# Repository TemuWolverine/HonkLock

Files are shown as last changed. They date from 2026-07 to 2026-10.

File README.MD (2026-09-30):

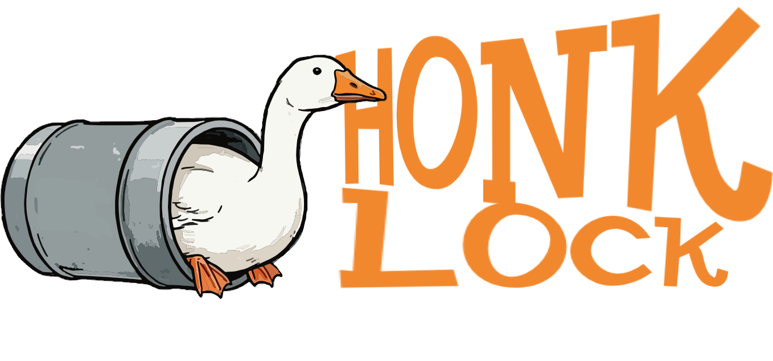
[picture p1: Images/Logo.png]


Watch the video (https://youtu.be/xcAHMuf7iR8)

- [Electronics](#electronics)
  - [Brain board](#brain-board)
  - [Sensor Board](#sensor-board)
  - [Hardware](#hardware)
  - [Power](#power)
  - [Alternative power wiring](#alternative-power-wiring)
  - [ESP32 SuperMini Variants](#esp32-supermini-variants)
- [Blast Gate](#blast-gate)
  - [Gate](#gate)
  - [Sensor Box](#sensor-box)

Open-source automated blast gate system and tool detection system.

## Implementation
Currently, this is implemented using ESPHome with dependencies on Home Assistant to handle the syncing between gates.

Eventually, the goal is to have two versions - one with ESPHome, one standalone using something like ESP32-IDF/ESP-Now for communication between gates.
ESPHome's advantage is any buttons/remotes (Zigbee, ZWave, Matter, Wifi) connected to Home Assistant can be used to trigger each gate, as well as rapid development and deployment.

# Electronics
## Brain board 
[Schematic](PCB/HonkLockBrainboard.pdf)
| Item | Quantity | Note |
| --- | --- | --- |
| [ESP32 S3 SuperMini](https://s.click.aliexpress.com/e/_c3BMFE2p) | 1 | (Just about) Any ESP32 is going to work. The supermini's are just adorably tiny, inexpensive, and relatively easy to come across from a range of vendors. <br> The Supermini range also has an onboard WS2812 LED (GPIO48), meaning gate status can be indicated (red = closed, green = open) with the included LED.<br><br>**Other supermini variants <ins>except H2 (no wifi)</ins> _should_ work just fine, you will just need to adjust the code slightly.** |
| [0.1uF ceramic cap](https://www.lcsc.com/product-detail/C1711.html) | 2 | 0805/2012 package |
| [1uF ceramic cap](https://www.lcsc.com/product-detail/C28323.html)  | 1 | 0805/2012 package |
| [10k resistor](https://www.lcsc.com/product-detail/C17414.html) | 2 | 0805/2012 package |
| [33k resistor](https://www.lcsc.com/product-detail/C17633.html) | 2 | 0805/2012 package |
| [P82B715 (SOIC)](https://www.lcsc.com/product-detail/C2649394.html) | 1 | I2C Extender |
| [USB jack](https://www.lcsc.com/product-detail/C2765186.html) | 1 | Ignore if not using USB for power |
| [5.1k resistor](https://www.lcsc.com/product-detail/C27834.html) | 2 | Ignore if not using USB for power, 0805 size |
| [RJ-45 jack](https://www.lcsc.com/product-detail/C7501824.html) | 1 | |
| [3 pin JST XH](https://www.lcsc.com/product-detail/C157928.html) | 1 | S3B-XH-A-LF |

## Sensor Board
[Schematic](PCB/HonkLockSensorBoard.pdf)
| Item | Quantity | Note |
| --- | --- | --- |
| [MLX90393](https://www.lcsc.com/product-detail/C2649492.html) | 1 | magnetometer for detecting tool on/off |
| [0.1uF ceramic cap](https://www.lcsc.com/product-detail/C1711.html) | 3 | 0805/2012 package |
| [1uF ceramic cap](https://www.lcsc.com/product-detail/C28323.html)  | 1 | 0805/2012 package |
| [10k resistor](https://www.lcsc.com/product-detail/C17414.html) | 2 | 0805/2012 package |
| [33k resistor](https://www.lcsc.com/product-detail/C17633.html) | 2 | 0805/2012 package |
| [P82B715 (SOIC)](https://www.lcsc.com/product-detail/C2649394.html) | 1 | I2C Extender |
| [RJ-45 jack](https://www.lcsc.com/product-detail/C7501824.html) | 1 | |

##  Hardware
| Item | Quantity | Note |
| --- | --- | --- |
| 'Standard Servo' | 1 | I've used a MG996 clone |
| M2.5 heatset inserts, standoffs, screws | | Design not 100% finalised |
| M4 and M5 Hardware | | Design not 100% finalised |
| cat5 cable | | For connecting the brainboard to the sensor board |

## Power
HonkLock is powered by any 5v1a USB brick - A or C.

## Alternative power wiring
If you'd rather have centralised power that runs out to each gate, you'll need to [calculate the wire required](https://www.omnicalculator.com/physics/wire-size).

## ESP32 SuperMini Variants  
There are a range of ESP32 "Supermini dev boards", most of which have identical pinouts, but not all are suitable.

| Variant | Suitable | Note |
| --- | --- | --- |
| S3 | ✅ | Dual core Xtensa CPU, previous top of the line chip. Total overkill for this application, but so common that it isn't expensive |
| C3 | ✅ | A lower power/slower alternative to the S3 using a RISC-V singlecore CPU and has 2.4ghz wifi |
| C3 Plus | ✅ | Seems to be a C3 with external antenna option |
| C6 | ✅ | Single core RISC-V chip, with Wifi 6 (2.4ghz) and thread/zigbee/matter support |
| H2 | ❌ | ESP32-H2 does not have Wifi at all, it has Bluetooth 5LE and thread/zigbee. Currently Wifi is a HonkLock requirement |

# Blast Gate
## Gate
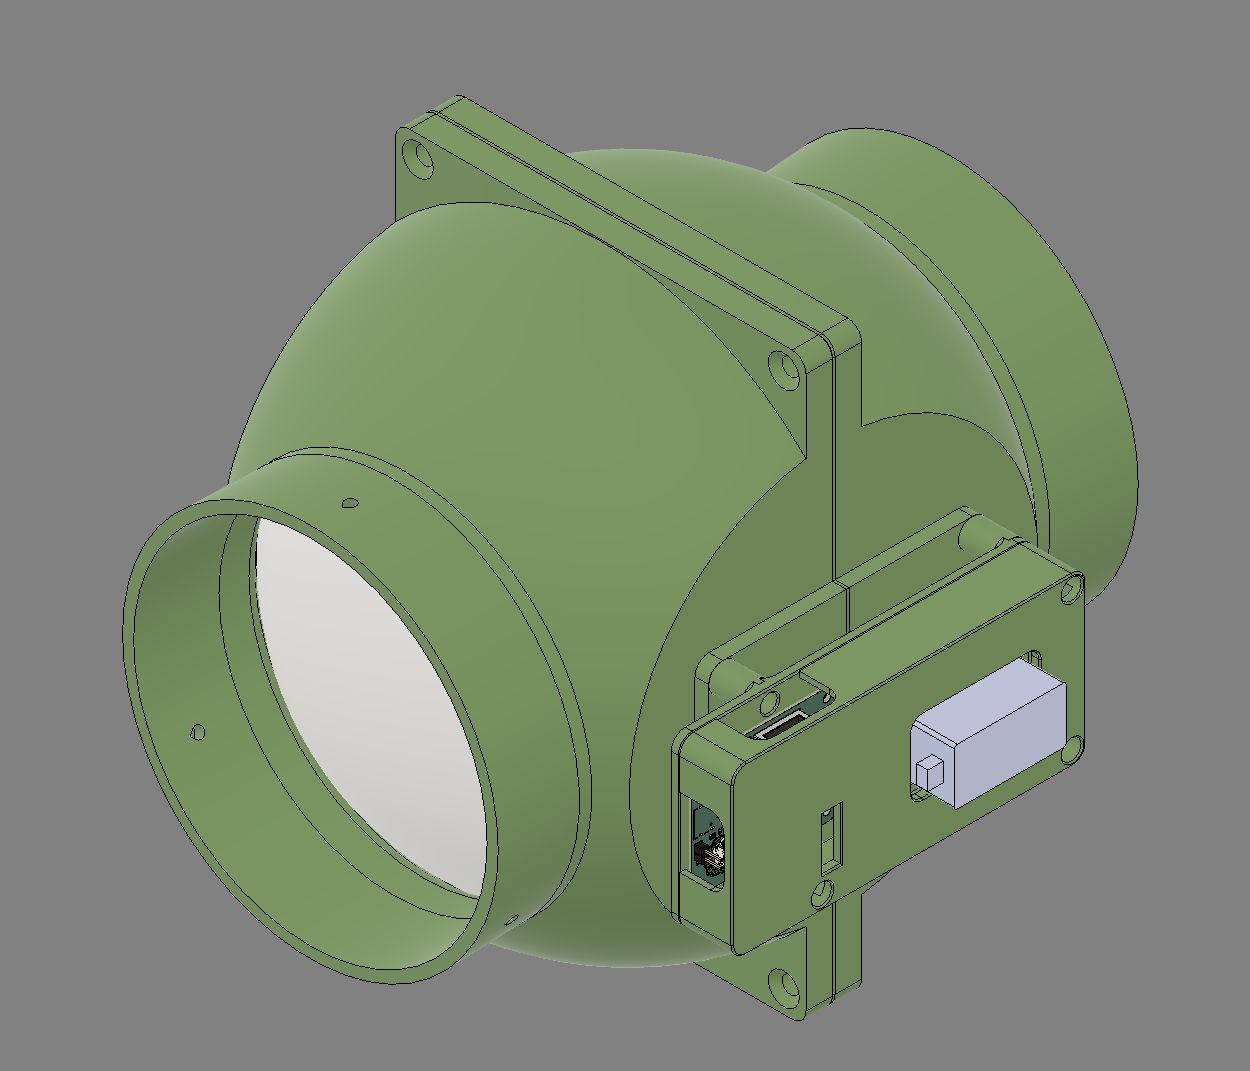
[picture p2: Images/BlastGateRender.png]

The current design is for *my* system, and thus is for 5" ducting. Fusion360 file provided for modification, eventually will model for different sizes.

* Blastgate: [Fusion360](CAD/BlastGate.f3z), [STEP](CAD/BlastGate.step), 3MF.
* Print in PETG, available on Makerworld with slicing settings built in.

## Sensor Box
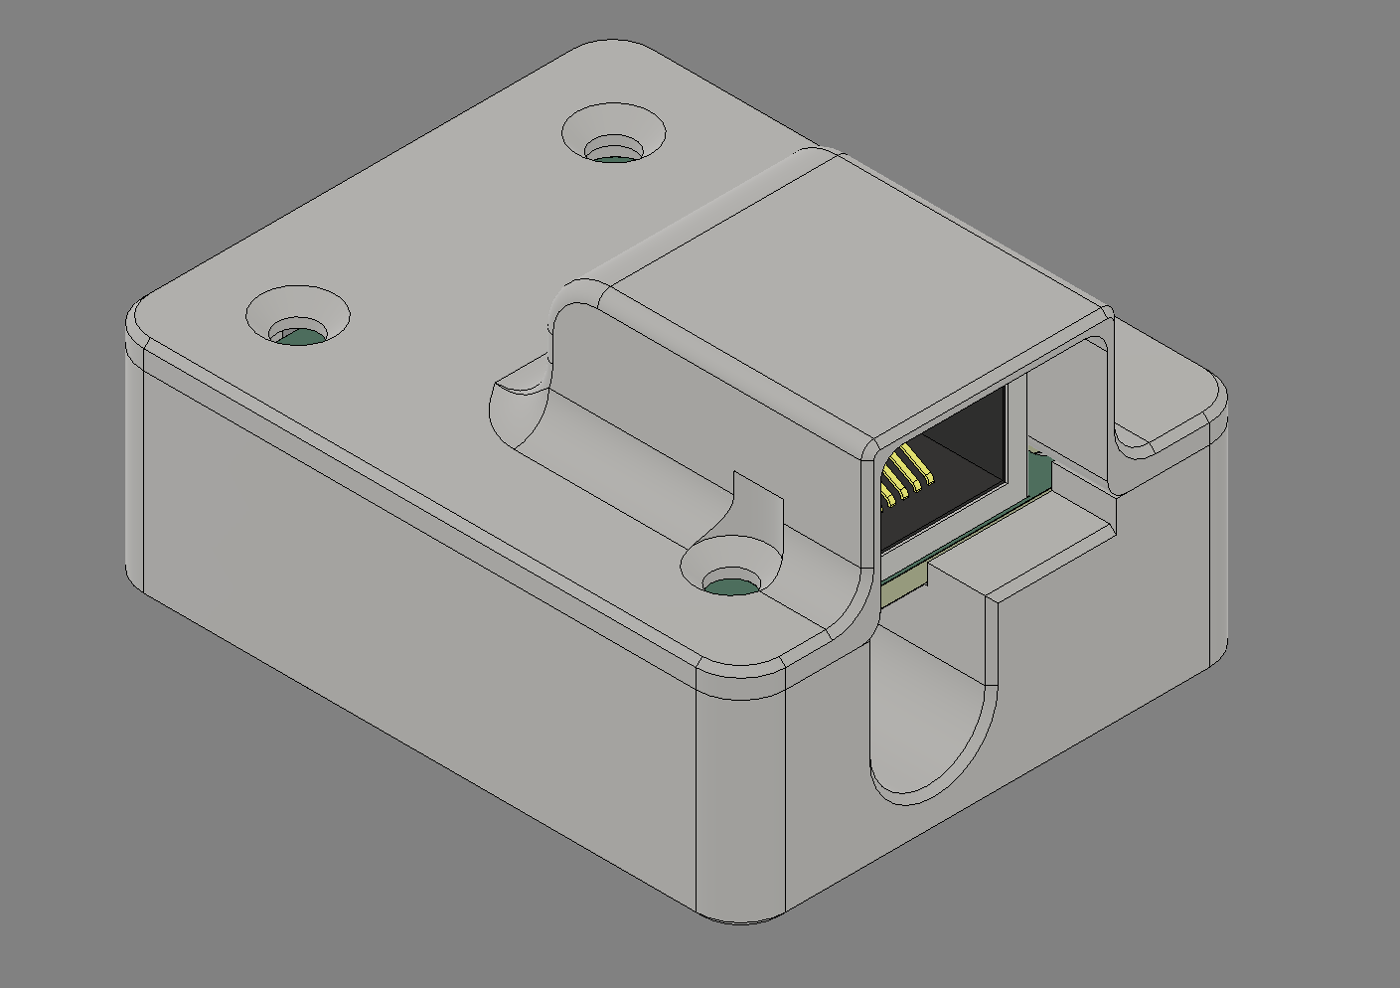
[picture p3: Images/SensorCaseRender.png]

* Sensor Box: [Fusion360](CAD/SensorBox.f3z), [STEP](CAD/SensorBox.step.step), 3MF.
* Print in PETG, available on Makerworld with slicing settings built in.
* Requires 4x M2.5 heatset inserts and M2.5 x 8mm screws

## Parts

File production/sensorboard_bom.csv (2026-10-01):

Designator | Footprint | Quantity | Value | LCSC Part #
C1 | 0805 | 1 | 1uF
C2, C3, C4 | 0805 | 3 | 0.1uF
R1, R2 | 0805 | 2 | 10k
R6, R7 | 0805 | 2 | 33k
RJ1 | RJ45-TH_HC-WK88-H16-DB | 1 | ~ | C7501824
TP1, TP2 | TestPoint-1.25mm | 2 | TestPoint
U1 | VQFN-16_L3.0-W3.0-P0.50-BL-EP1.7 | 1 | ~ | C2649492
U2 | SOIC-8_L4.9-W3.9-P1.27-LS6.0-BL | 1 | ~ | C2649394

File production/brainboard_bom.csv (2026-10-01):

Designator | Footprint | Quantity | Value | LCSC Part #
C1, C5 | 0805 | 2 | 0.1uF
C6 | 0805 | 1 | 1uF
J1 | CONN-TH_S3B-XH-A-LF-SN | 1 | Conn_01x03_Pin
J5 | PinHeader_1x02_P2.54mm_Vertical | 1 | Conn_01x02_Pin
R10, R8 | 0805 | 2 | 10k
R2, R3 | 0805 | 2 | 5.1k
R6, R7 | 0805 | 2 | 33k
RJ1 | RJ45-TH_HC-WK88-H16-DB | 1 | ~ | C7501824
U1 | SOIC-8_L4.9-W3.9-P1.27-LS6.0-BL | 1 | ~ | C2649394
USB1 | USB-C-SMD_TYPE-C-16PIN-2MD-073 | 1 | ~ | C2765186

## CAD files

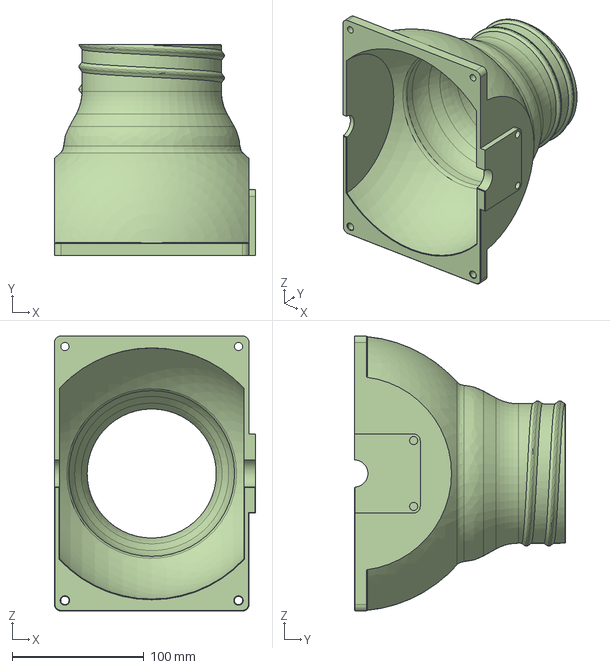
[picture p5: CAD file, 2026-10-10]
CAD/BlastGateThreadedSide.step
152.9 x 160.4 x 208.8 mm

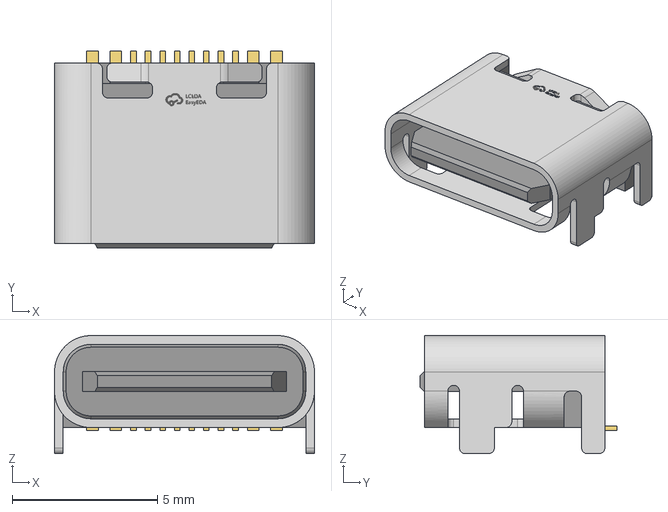
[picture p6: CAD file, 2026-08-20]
PCB/EASYEDA_MODELS/TYPE-C-SMD_UC.01.51-11-0017.step
8.94 x 6.76 x 4.07 mm

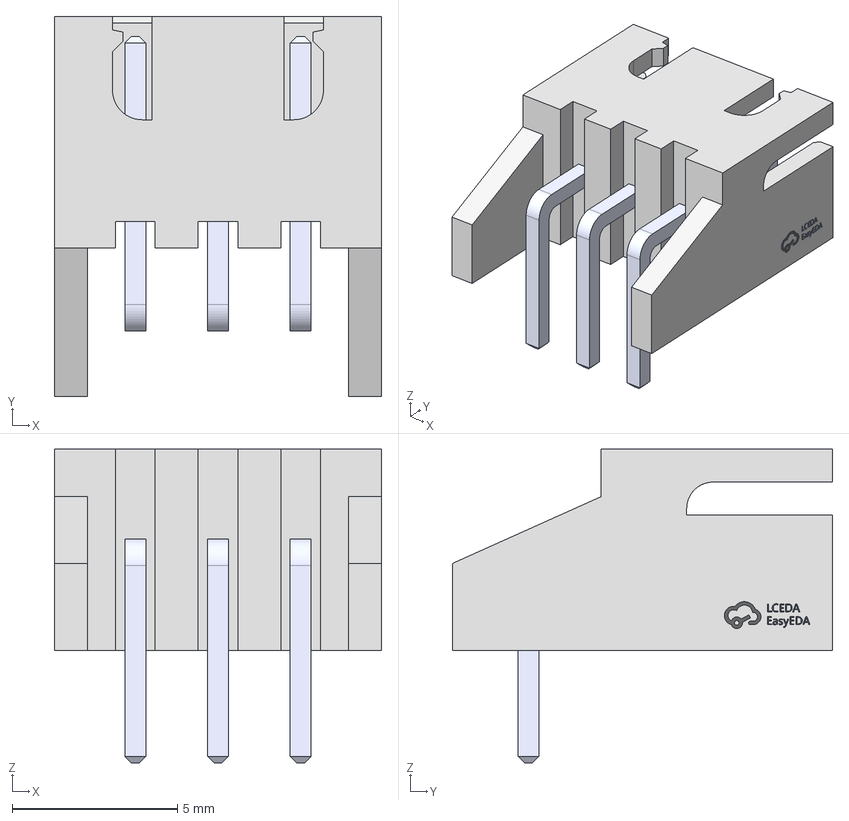
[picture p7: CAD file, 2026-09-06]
PCB/Mainboard/EASYEDA_MODELS/CONN-TH_S3B-XH-A-LF-SN.step
9.90 x 11.5 x 9.50 mm

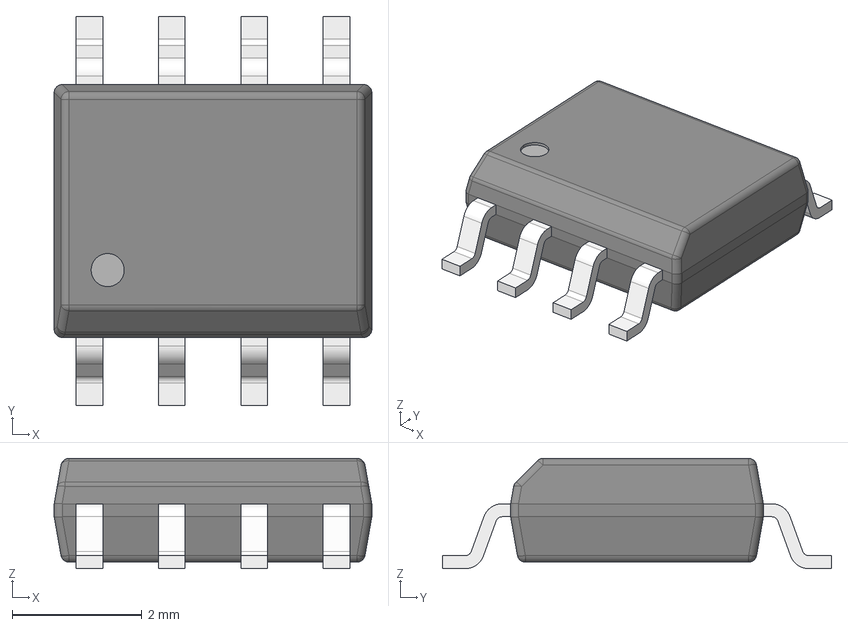
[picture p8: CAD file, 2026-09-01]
PCB/SensorBoard/EASYEDA_MODELS/SOIC-8_L4.9-W3.9-H1.7-LS6.0-P1.27.step
4.90 x 6.00 x 1.70 mm

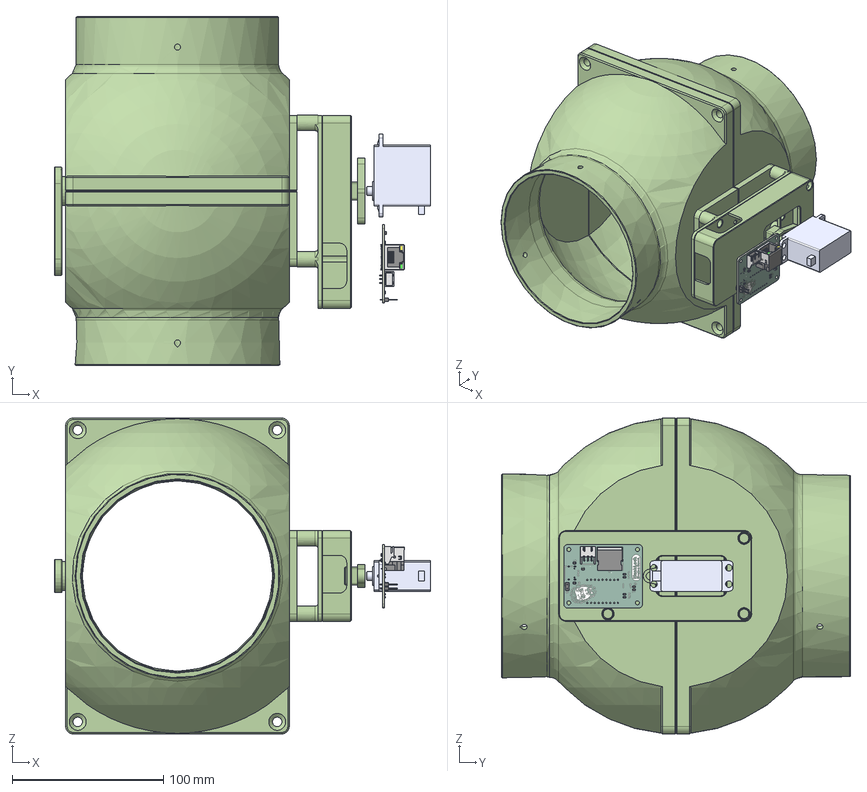
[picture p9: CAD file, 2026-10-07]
CAD/BlastGate.step
248.8 x 230.7 x 208.8 mm
Housing
Hinge x 2
Handle
dss-p05_servo
R_0805_2012Metric_6 x 6
PinHeader_1x02_P254mm_Vertical
C_0805_2012Metric_3 x 3
Hon262C_silkscreen
Hon262C_silkscreen_1
Hon262C_soldermask
Hon262C_soldermask_1
Hon262C_PCB
Drive Adapter
Motor Mount
Lid
HingeAlt

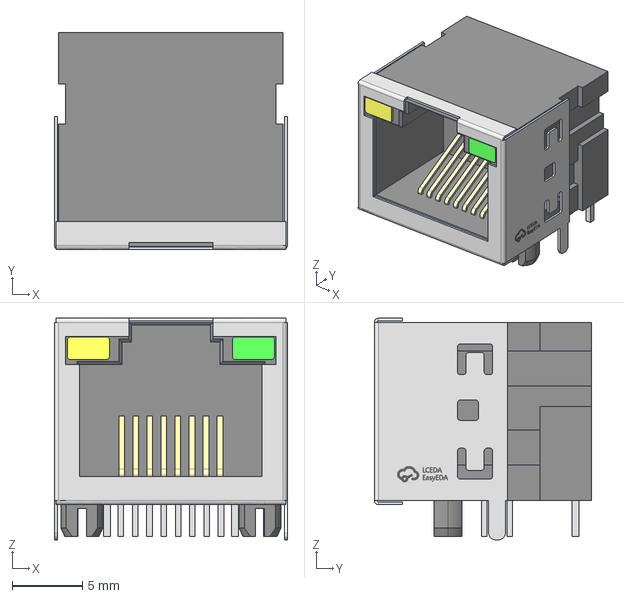
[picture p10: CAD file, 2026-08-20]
PCB/EASYEDA_MODELS/RJ45-TH_HC-WK88-H16-DB.step
16.6 x 15.5 x 15.8 mm

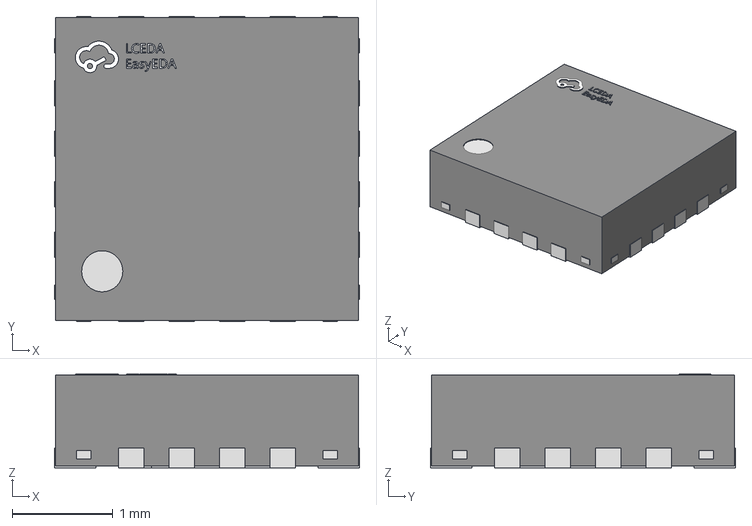
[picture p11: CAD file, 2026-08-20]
PCB/SensorBoard/EASYEDA_MODELS/VQFN-16_L3.0-W3.0-P0.50-BL-EP1.7.step
3.02 x 3.02 x 0.93 mm

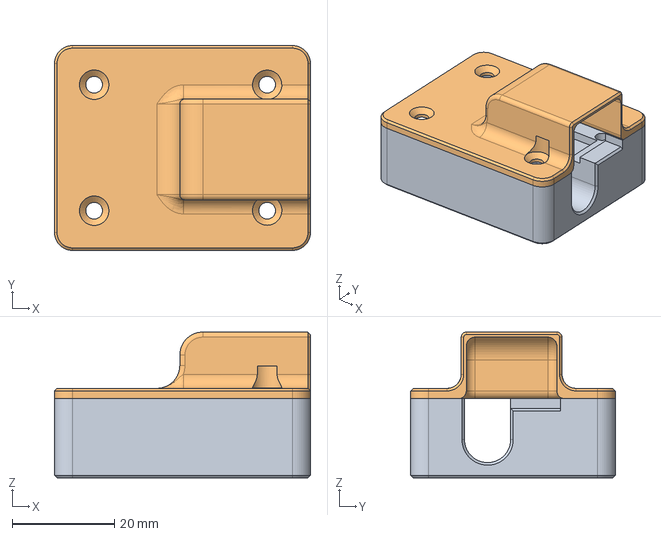
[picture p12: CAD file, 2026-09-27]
CAD/SensorBox.step
50.0 x 40.0 x 28.5 mm
Base
Top

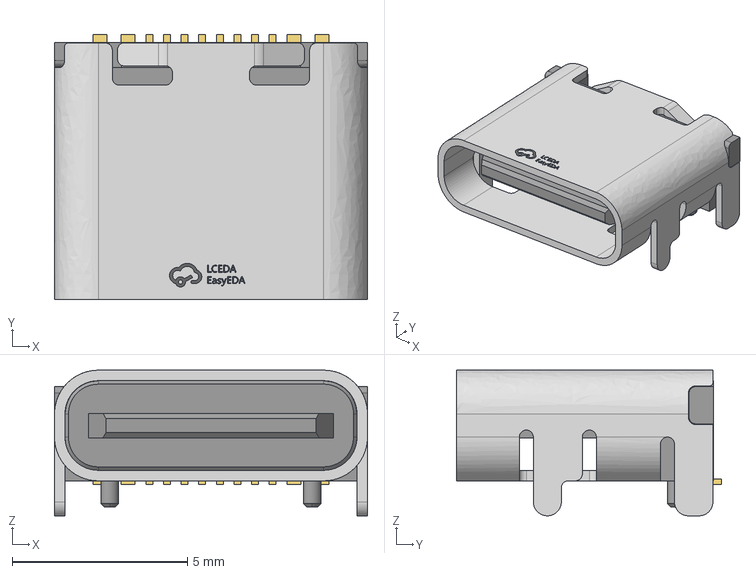
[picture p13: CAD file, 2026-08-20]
PCB/EASYEDA_MODELS/USB-C-SMD_TYPE-C-6PIN-2MD-073.step
8.94 x 7.58 x 4.16 mm

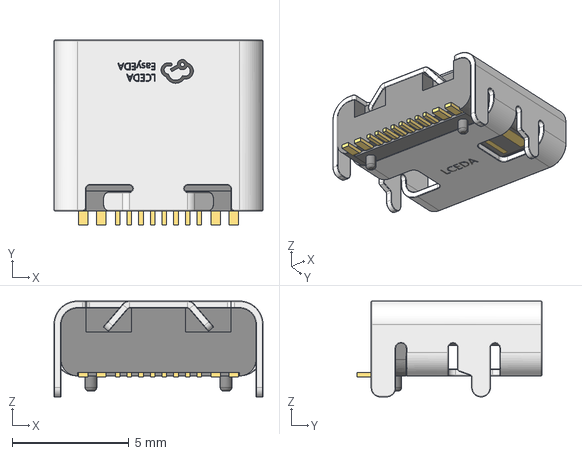
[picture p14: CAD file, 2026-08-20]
PCB/EASYEDA_MODELS/USB-C_SMD-TYPE-C-31-M-12_1.step
8.94 x 7.90 x 4.10 mm

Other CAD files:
PCB/Mainboard/EASYEDA_MODELS/SOIC-8_L4.9-W3.9-H1.7-LS6.0-P1.27.step
PCB/EASYEDA_MODELS/SOIC-8_L4.9-W3.9-H1.7-LS6.0-P1.27.step
CAD/BlastGate.f3z
CAD/BlastGateThreadedSide.f3z
CAD/SensorBox.f3z

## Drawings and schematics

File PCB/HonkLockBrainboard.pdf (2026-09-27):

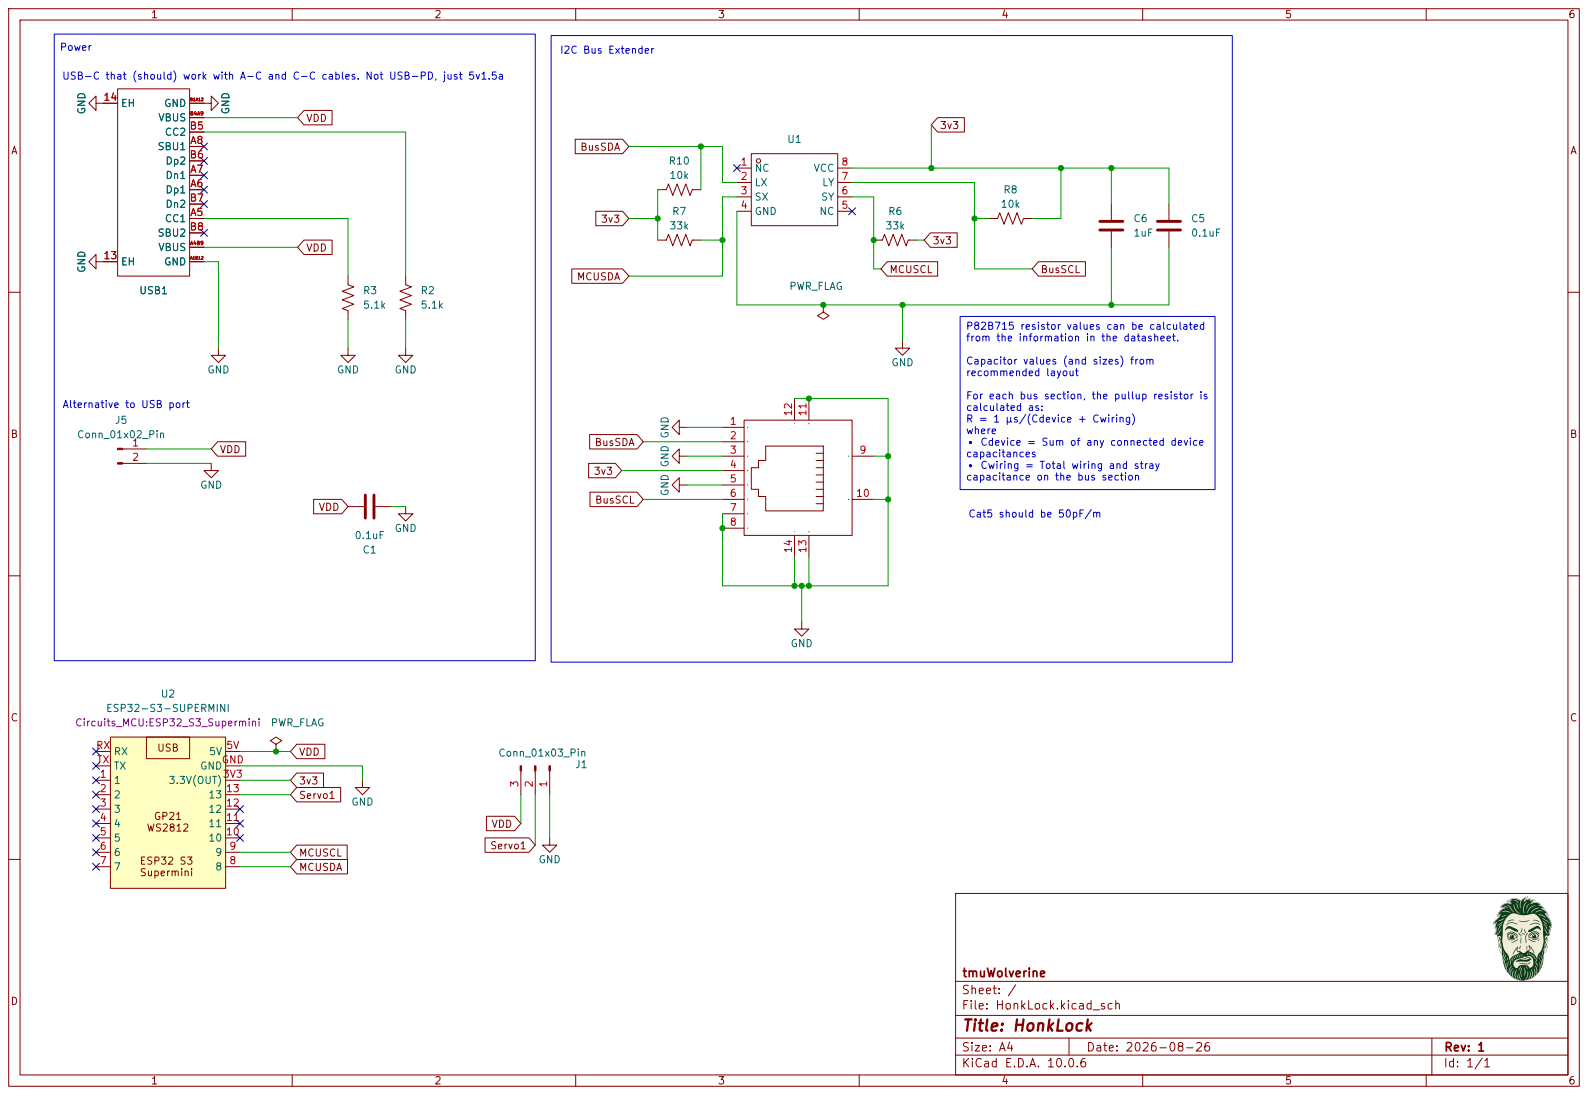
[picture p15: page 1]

from the information in the datasheet. Capacitor values (and sizes) from

recommended layout For each bus section, the pullup resistor is calculated as: R = 1 μs/(Cdevice + Cwiring) where • Cdevice = Sum of any connected device

capacitances • Cwiring = Total wiring and stray

capacitance on the bus section

Size: A4 | Rev: 1
KiCad E.D.A. 10.0.6 | Id: 1/1

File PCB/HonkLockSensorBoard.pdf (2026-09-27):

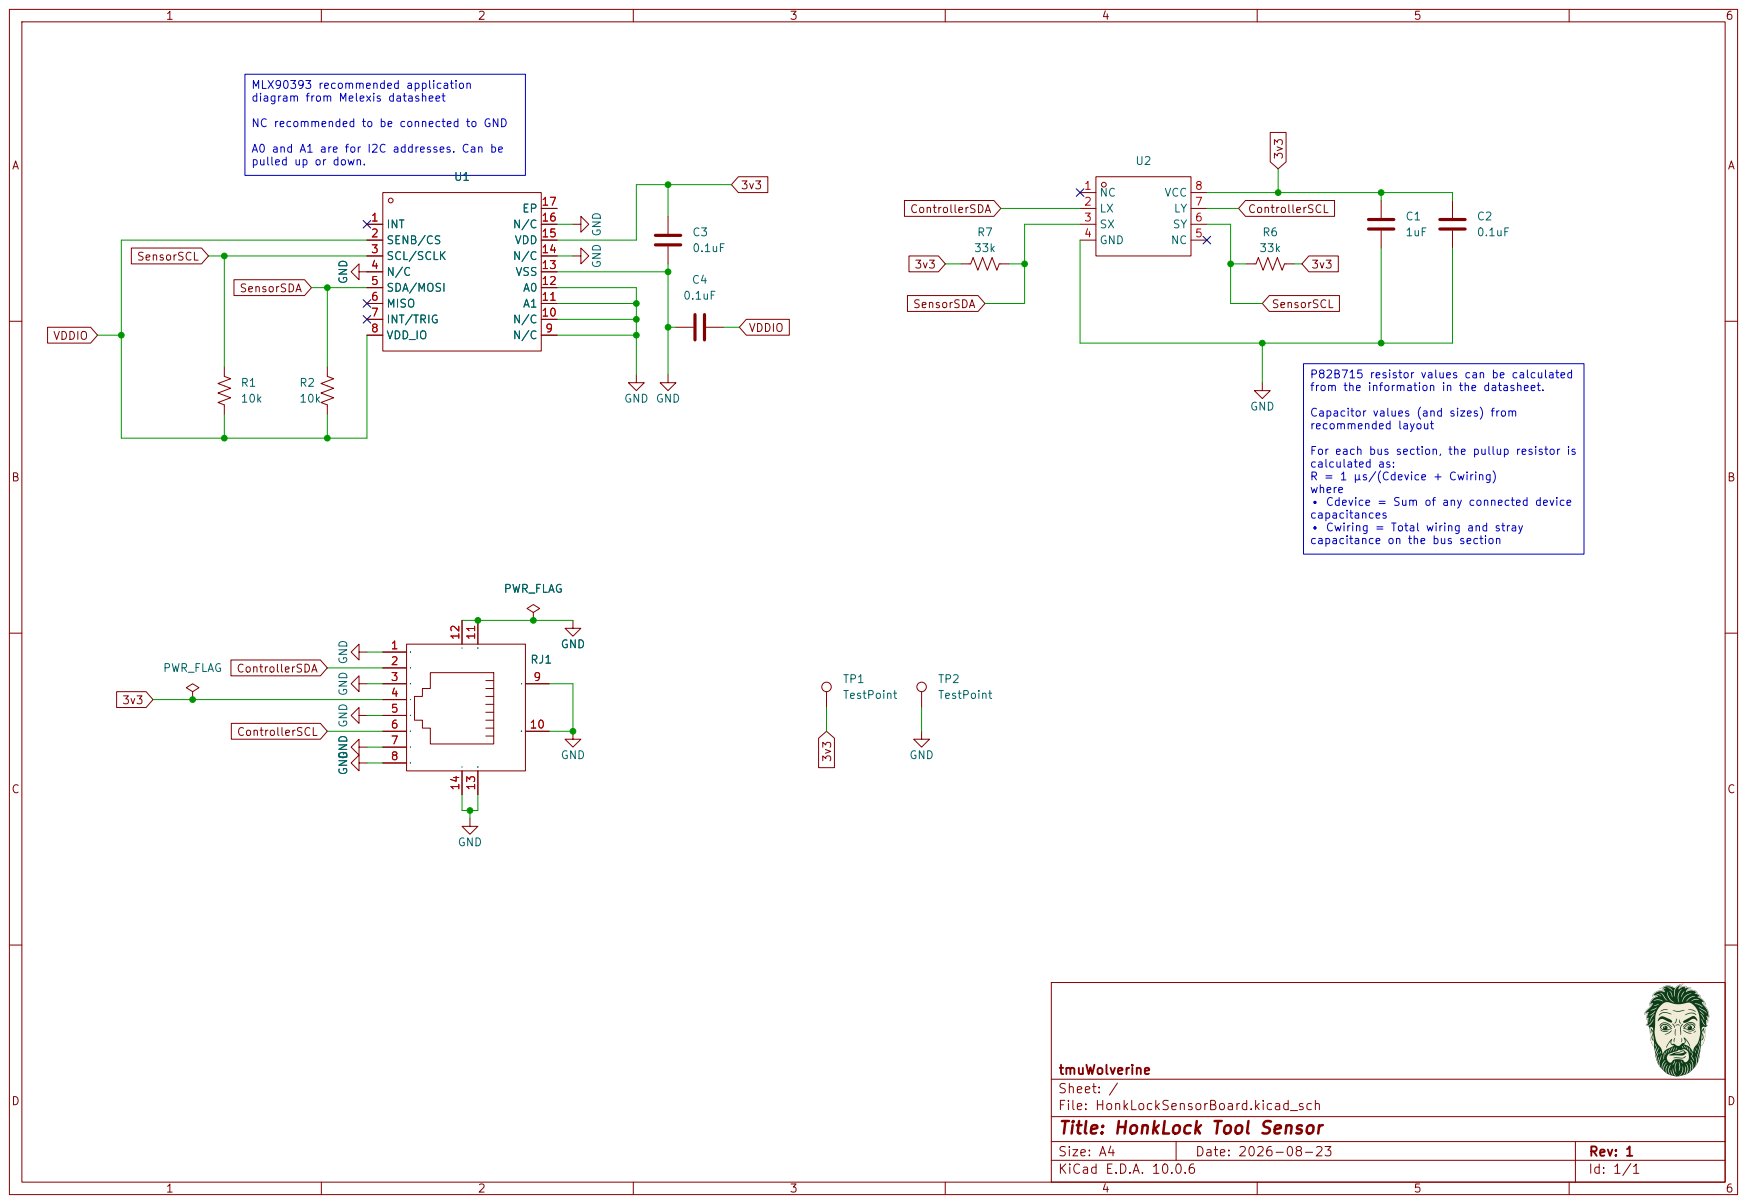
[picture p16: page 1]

capacitance on the bus section MLX90393 recommended application
diagram from Melexis datasheet NC recommended to be connected to GND

from the information in the datasheet. Capacitor values (and sizes) from

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

capacitances • Cwiring = Total wiring and stray

tmuWolverine
Sheet: /
File: HonkLockSensorBoard.kicad_sch
Title: HonkLock Tool Sensor

Size: A4 | Rev: 1
KiCad E.D.A. 10.0.6 | Id: 1/1

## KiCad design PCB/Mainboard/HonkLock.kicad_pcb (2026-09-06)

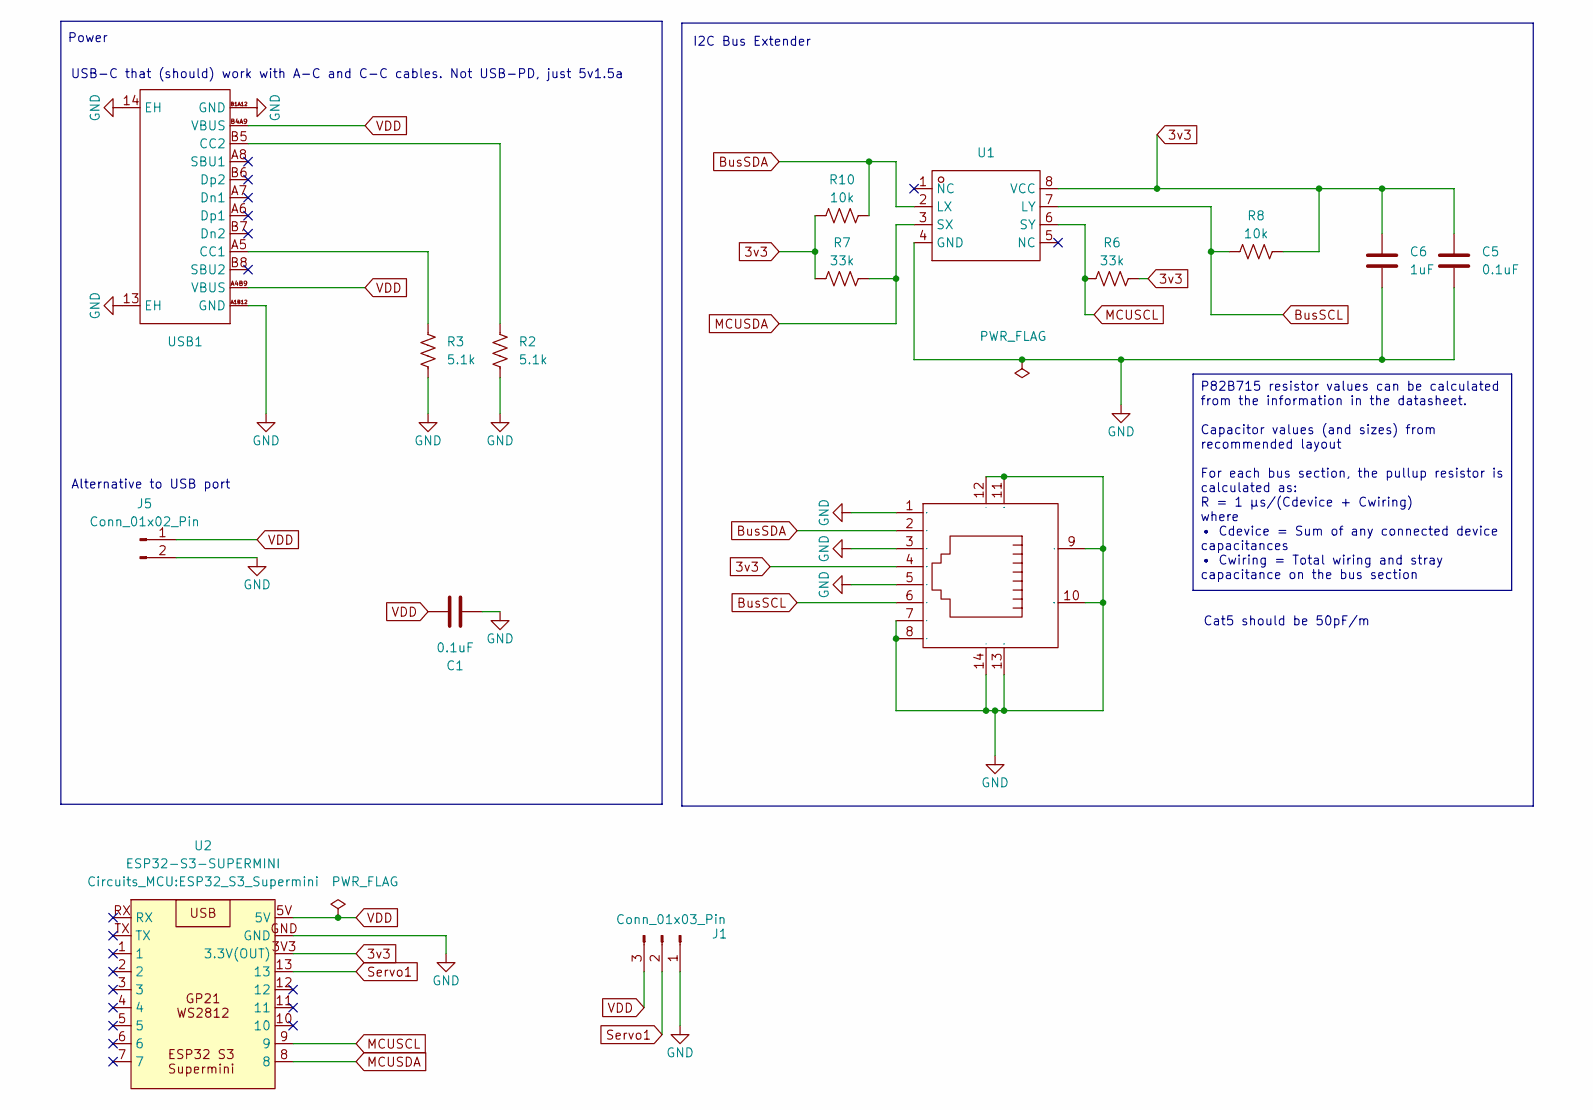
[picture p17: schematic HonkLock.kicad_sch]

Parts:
C1, C5: 0.1uF; C_0805_2012Metric
C6: 1uF; C_0805_2012Metric
J1: Conn_01x03_Pin; CONN-TH_S3B-XH-A-LF-SN
J5: Conn_01x02_Pin; PinHeader_1x02_P2.54mm_Vertical
R2, R3: 5.1k; R_0805_2012Metric
R6, R7: 33k; R_0805_2012Metric
R8, R10: 10k; R_0805_2012Metric
RJ1: RJ45-TH_HC-WK88-H16-DB; Manufacturer Part HC-WK88-H16-DB; LCSC Part Name 弯插 带LED 网口 RJ45-8P8C-16H半包 带灯 不锈钢壳 B款
U1: SOIC-8_L4.9-W3.9-P1.27-LS6.0-BL; Manufacturer Part P82B715DR; LCSC Part Name P82B715 I²C总线扩展器
U2: ESP32-S3-SUPERMINI; ESP32_S3_Supermini
USB1: USB-C-SMD_TYPE-C-16PIN-2MD-073; Manufacturer Part TYPE-C 16PIN 2MD(073); LCSC Part Name Type-C 母 卧贴

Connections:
3v3: C5.1, C6.1, R6.2, R7.1, R8.2, R10.1, RJ1.4, U1.8 (VCC), U2.3V3 (3.3V(OUT))
BusSCL: R8.1, RJ1.6, U1.7 (LY)
BusSDA: R10.2, RJ1.2, U1.2 (LX)
GND: C1.1, C5.2, C6.2, J1.1, J5.2, R2.1, R3.1, RJ1.1, RJ1.3, RJ1.5, RJ1.7, RJ1.8, RJ1.9, RJ1.10, RJ1.11 (+), RJ1.12 (-), RJ1.13 (+), RJ1.14 (-), U1.4 (GND), U2.GND, USB1.13 (EH), USB1.14 (EH), USB1.A1B12 (GND), USB1.B1A12 (GND)
MCUSCL: R6.1, U1.6 (SY), U2.9
MCUSDA: R7.2, U1.3 (SX), U2.8
unnamed: R3.2, USB1.A5 (CC1)
unnamed: R2.2, USB1.B5 (CC2)
Servo1: J1.2, U2.13
VDD: C1.2, J1.3, J5.1, U2.5V, USB1.A4B9 (VBUS), USB1.B4A9 (VBUS)

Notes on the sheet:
Alternative to USB port
Power
I2C Bus Extender
USB-C that (should) work with A-C and C-C cables. Not USB-PD, just 5v1.5a
Cat5 should be 50pF/m
P82B715 resistor values can be calculated from the information in the datasheet. Capacitor values (and sizes) from recommended layout For each bus section, the pullup resistor is calculated as: R = 1 μs/(Cdevice + Cwiring) where • Cdevice = Sum of any connected device capacitances • Cwiring = Total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

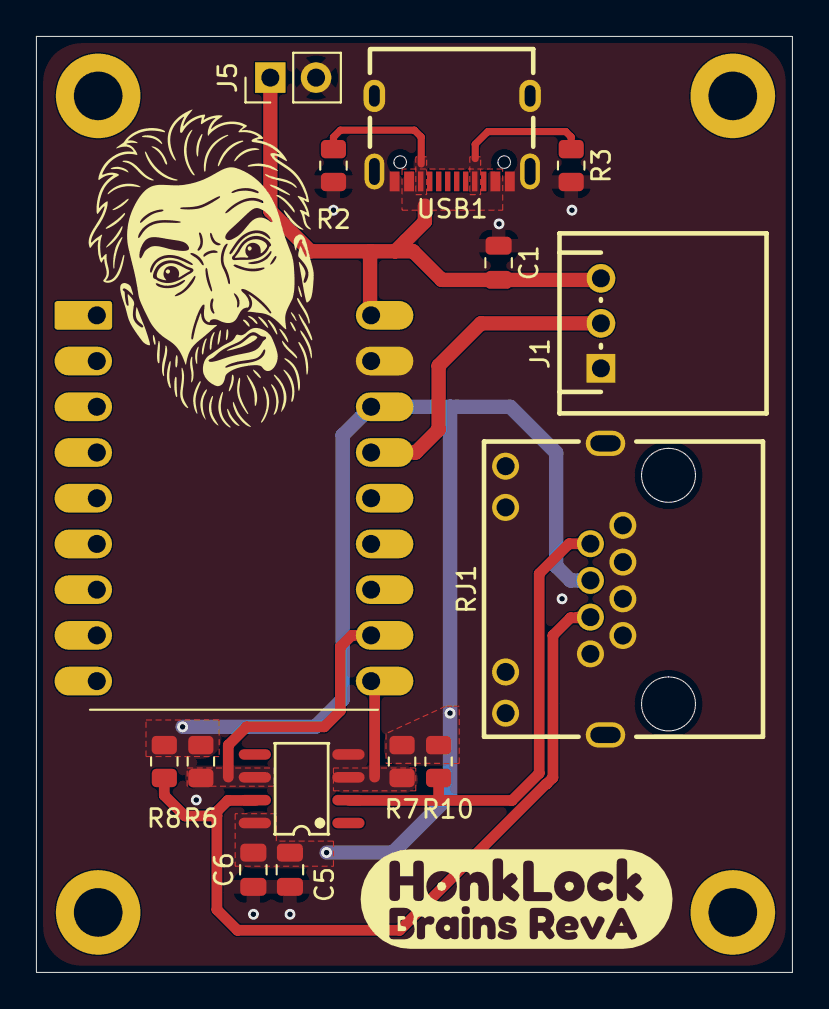
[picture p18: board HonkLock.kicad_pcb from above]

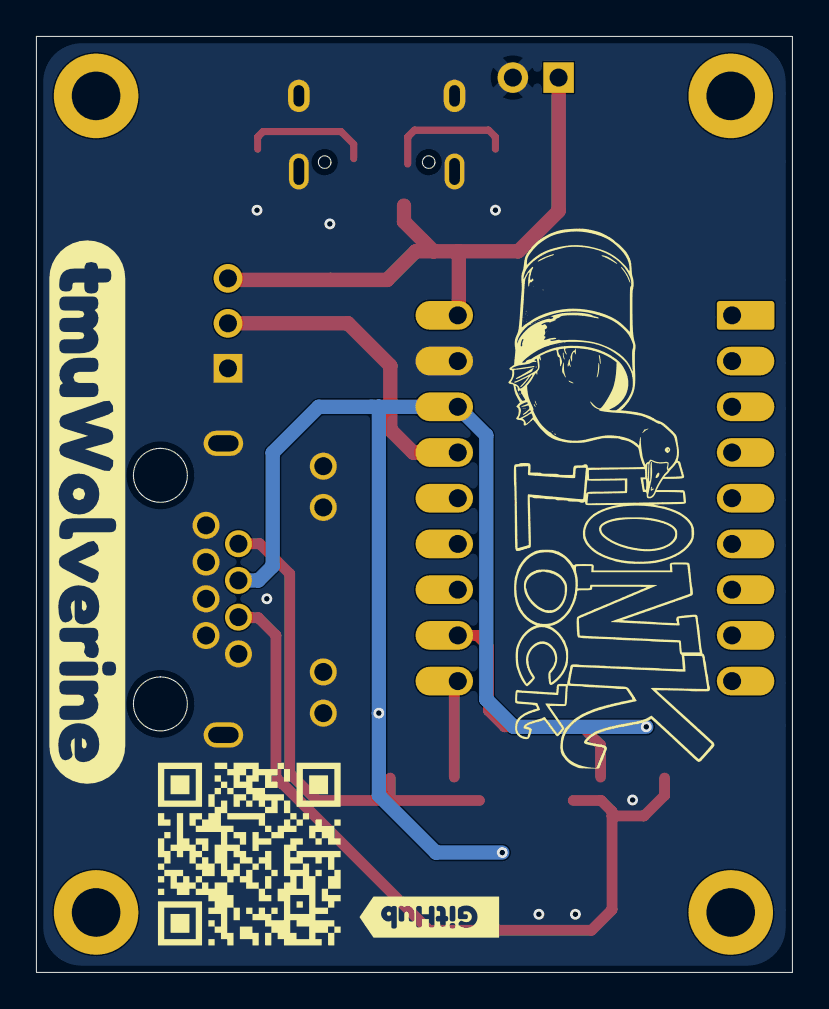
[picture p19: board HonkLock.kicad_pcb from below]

Board: 2 copper layers, 42.0 x 52.0 mm, 19 parts (3 on the bottom side), 10 nets.

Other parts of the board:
kobee-studio-6A97AAF5: Kobee Studio; kobee-studio-6A96C1A4
kobee-studio-6A97ABF4: Kobee Studio; kobee-studio-6A97ABF4
kobee-studio-6A97AC47: Kobee Studio; kobee-studio-6A97AC2D
kobee-studio-6A97AC75: Kobee Studio; kobee-studio-6A97AC75

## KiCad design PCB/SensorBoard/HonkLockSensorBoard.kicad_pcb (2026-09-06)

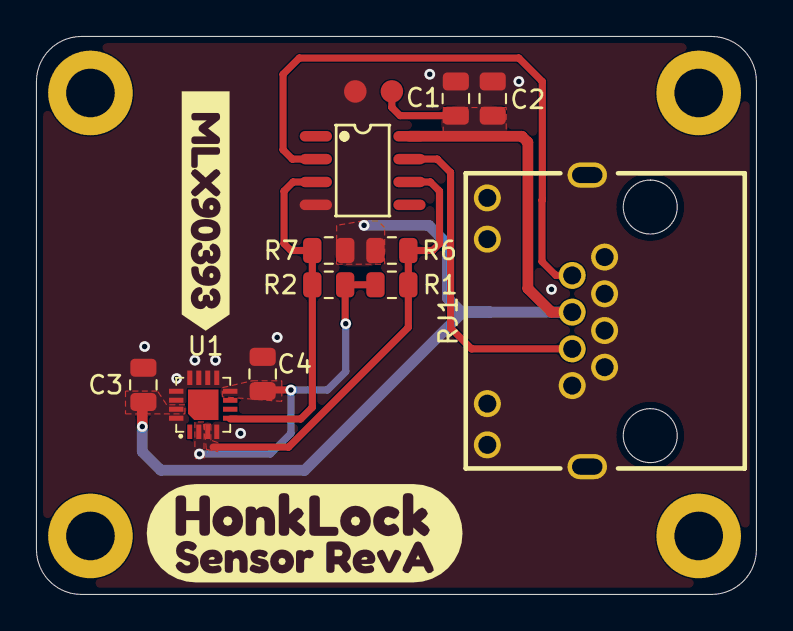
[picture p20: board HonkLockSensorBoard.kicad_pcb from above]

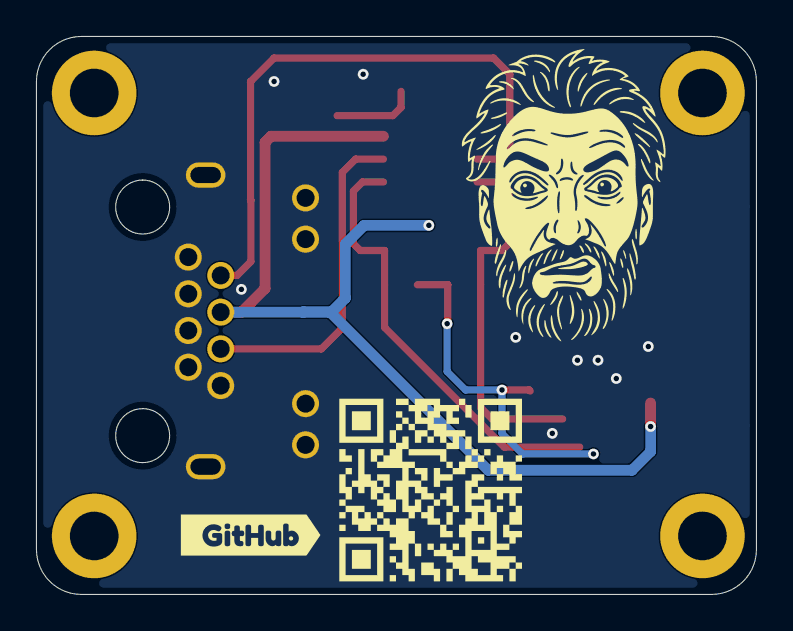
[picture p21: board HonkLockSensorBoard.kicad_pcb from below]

Board: 2 copper layers, 40.0 x 31.0 mm, 17 parts (2 on the bottom side), 7 nets.

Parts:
C1: 1uF; C_0805_2012Metric
C2, C3, C4: 0.1uF; C_0805_2012Metric
R1, R2: 10k; R_0805_2012Metric
R6, R7: 33k; R_0805_2012Metric
RJ1: RJ45-TH_HC-WK88-H16-DB
TP1, TP2: TestPoint; TestPoint-1.25mm
U1: VQFN-16_L3.0-W3.0-P0.50-BL-EP1.7
U2: SOIC-8_L4.9-W3.9-P1.27-LS6.0-BL
kobee-studio-6A96C2E0: Kobee Studio; kobee-studio-6A96C244
kobee-studio-6A97ABF4: Kobee Studio; kobee-studio-6A97ABF4
kobee-studio-6A97AC75: Kobee Studio; kobee-studio-6A97AC75
kobee-studio-6A97AD50: Kobee Studio; kobee-studio-6A96C1A4

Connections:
3v3: C1.1, C2.1, C3.1, R6.2, R7.1, RJ1.4, TP1.1 (1_1), U1.15 (VDD), U2.8 (VCC)
ControllerSCL: RJ1.6, U2.7 (LY)
ControllerSDA: RJ1.2, U2.2 (LX)
GND: C1.2, C2.2, C3.2, C4.1, RJ1.1, RJ1.3, RJ1.5, RJ1.7, RJ1.8, RJ1.9, RJ1.10, RJ1.11 (+), RJ1.12 (-), RJ1.13 (+), RJ1.14 (-), TP2.1 (1_1), U1.4 (N/C), U1.9 (N/C), U1.10 (N/C), U1.11 (A1), U1.12 (A0), U1.13 (VSS), U1.14 (N/C), U1.16 (N/C), U2.4 (GND)
SensorSCL: R1.2, R6.1, U1.3 (SCL/SCLK), U2.6 (SY)
SensorSDA: R2.1, R7.2, U1.5 (SDA/MOSI), U2.3 (SX)
VDDIO: C4.2, R1.1, R2.2, U1.2 (SENB/CS), U1.8 (VDD_IO)

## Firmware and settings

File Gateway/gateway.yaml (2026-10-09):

substitutions:
  clkpin: GPIO13
  mosi: GPIO44
  miso: GPIO43
  cs_pin: GPIO01
  gdo0_pin: GPIO12
  gdo1_pin: GPIO11
  led_pin: GPIO48

esphome:
  name: honklockgateway2
  friendly_name: HonklockGateway2
  min_version: 2026.4.0
  name_add_mac_suffix: false

esp32:
  variant: esp32s3
  framework:
    type: esp-idf

# Modular packages: Include either or both depending on the devices in your system
packages:
  ivac: !include gateway_ivac.yaml
  arlec_rc210: !include gateway_arlec_rc210.yaml

# Allow Over-The-Air updates
ota:
  - platform: esphome

wifi:
  ssid: !secret wifi_ssid
  password: !secret wifi_password

logger:
  level: DEBUG

# SPI configuration for the CC1101 transceiver
spi:
  clk_pin: ${clkpin}
  mosi_pin: ${mosi}
  miso_pin: ${miso}

# Configure the CC1101 transceiver hardware registers
cc1101:
  id: my_cc1101
  cs_pin: ${cs_pin}
  filter_bandwidth: 325kHz
  frequency: 433.92MHz
  manchester: true

# Configures the RF Transmitter output pin (using CC1101 GDO0)
remote_transmitter:
  id: rf_tx
  pin: ${gdo0_pin}
  carrier_duty_percent: 100%
  non_blocking: true
  rmt_symbols: 48
  on_transmit:
    - lambda: |-
        ESP_LOGI("rf_tx", "CC1101 entering TX mode and transmitting pulses...");
    - cc1101.begin_tx: my_cc1101
  on_complete:
    - lambda: |-
        ESP_LOGI("rf_tx", "Transmission finished, CC1101 returning to IDLE mode.");
    - cc1101.set_idle: my_cc1101

# Configures the RF Receiver listening pin (using CC1101 GDO2) for on-demand learning
remote_receiver:
  id: rf_rx
  pin: ${gdo1_pin}
  dump: []
  filter: 50us
  idle: 20ms
  buffer_size: 2kb
  rmt_symbols: 48

# ESP32-S3-SuperMini Onboard WS2812B RGB LED (GPIO48)
light:
  - platform: esp32_rmt_led_strip
    rgb_order: GRB
    pin: ${led_pin}
    num_leds: 1
    chipset: ws2812
    rmt_symbols: 48
    name: "Onboard LED"
    id: onboard_led
    internal: true
    effects:
      - strobe:
          name: "Blink"
          colors:
            - state: true
              brightness: 100%
              red: 0%
              green: 0%
              blue: 100%
              duration: 250ms
            - state: false
              duration: 250ms

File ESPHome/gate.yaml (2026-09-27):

substitutions:
  friendly_name: HonkLock
  device_name: honklock
  servo_pin: GPIO13
  sda_pin: GPIO08
  scl_pin: GPIO09

packages:
  esphome_templates:
    url: https://github.com/TemuWolverine/esphome_templates
    ref: main
    refresh: 1d
    files:
      - boards/esp32_s3_supermini.yaml

esphome:
  name: ${device_name}
  friendly_name: ${friendly_name}
  name_add_mac_suffix: true

logger:

api:
  homeassistant_services: true
  
# Allow Over-The-Air updates
ota:
  - platform: esphome

wifi:
  ssid: !secret wifi_ssid
  password: !secret wifi_password

# Setup
globals:
  - id: gatestate
    type: bool
    restore_value: yes
    initial_value: 'false'

  - id: servo_open_position
    type: float
    restore_value: yes
    initial_value: '0.0'

  - id: servo_closed_position
    type: float
    restore_value: yes
    initial_value: '-100.0'

servo:
  - id: my_servo
    output: pwm_output
    transition_length : 0.5s
    
output:
  - platform: ledc 
    id: pwm_output
    pin: ${servo_pin}
    frequency: 50Hz
    
i2c:
  - id: bus_a
    sda: ${sda_pin}
    scl: ${scl_pin}
    scan: true

    
#Tool detection

sensor:
  - platform: mlx90393 #https://esphome.io/components/sensor/mlx90393/
    i2c_id : bus_a
    address: 0x0C #important for honklock due to the sensor design
    id: mlx
    gain: 5X

    x_axis:
      name: "MLX Field Strength X"
      resolution: DIV_8
      id: mlx_x
      accuracy_decimals: 5
      internal: true
    y_axis:
      name: "MLX Field Strength Y"
      resolution: DIV_8
      id: mlx_y
      accuracy_decimals: 5
      internal: true
    z_axis:
      name: "MLX Field Strength Z"
      resolution: DIV_8
      id: mlx_z
      accuracy_decimals: 5
      internal: true
      
    update_interval : 20ms

  - platform: template
    id: magnetic_strength
    internal: true
    lambda: |-
      return sqrt(
        id(mlx_x).state * id(mlx_x).state +
        id(mlx_y).state * id(mlx_y).state +
        id(mlx_z).state * id(mlx_z).state
      );

    update_interval: 20ms
    
  - platform: copy
    source_id: magnetic_strength
    id: magnetic_baseline
    internal: true
    filters:
      - exponential_moving_average:
          alpha: 0.01
          send_every: 1  
          
  - platform: template
    id: magnetic_delta
    internal: true
    lambda: |-
      return fabs(id(magnetic_strength).state -
                  id(magnetic_baseline).state);
    update_interval: 10ms

binary_sensor:
  - platform: template
    id: tool_running
    name: "Tool Running"

    lambda: |-
      return id(magnetic_delta).state > 2.5;

    filters:
      - delayed_on: 150ms
      - delayed_off: 500ms
        
    on_press:
      - switch.turn_on: gate

# Gate stuff
number:
  # Calibration slider for open position
  - platform: template
    id: calibrate_open
    name: "Calibrate Open Position"
    min_value: -100.0
    max_value: 100.0
    step: 1.0
    optimistic: true
    restore_value: yes
    unit_of_measurement: "%"
    set_action:
      then:
        - lambda: |-
            id(servo_open_position) = x;
        - servo.write:
            id: my_servo
            level: !lambda 'return id(servo_open_position) / 100;'
            
   # Calibration slider for closed position
  - platform: template
    id: calibrate_closed
    name: "Calibrate Closed Position"
    min_value: -100.0
    max_value: 100.0
    optimistic: true
    restore_value: yes
    step: 1.0
    unit_of_measurement: "%"
    set_action:
      then:
        - lambda: |-
            id(servo_closed_position) = x;
        - servo.write:
            id: my_servo
            level: !lambda 'return id(servo_closed_position) / 100;'

switch:
  - platform: template
    id: gate
    name: "Gate"
    optimistic: true
    assumed_state: true

    turn_on_action: 
      then:
        - servo.write:
            id: my_servo
            level: !lambda 'return id(servo_open_position) /100;'

        - light.turn_on:
            id: statusled
            brightness: 100%
            red: 0%
            green: 100%
            blue: 0%
        - globals.set:
            id: gatestate
            value: 'true'

    turn_off_action: 
      then:
        - servo.write:
            id: my_servo
            level: !lambda 'return id(servo_closed_position) /100;'
        - light.turn_on:
            id: statusled
            brightness: 100%
            red: 100%
            green: 0%
            blue: 0%

        - globals.set:
            id: gatestate
            value: 'false'

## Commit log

2026-07-08 draft of the carrier board pcb
    [HonkLock.kicad_pcb, HonkLock.kicad_sch]
2026-07-11 YAML updates tying the servo states and tool detection together.
2026-07-11 Carrier board PCB
    [HonkLock.kicad_pcb, HonkLock.kicad_sch]
2026-07-12 switched to the correct ESP32 dev board, added a capacitor, added a forth switch
    [HonkLock.kicad_pcb, HonkLock.kicad_sch]
2026-07-18 minor rev
    [HonkLock.kicad_pcb]
2026-08-20 push some 3d stuff
    [BlastGate.f3z, BlastGate.step]
2026-08-20 whoops everyhting was invisible
    [BlastGate.step]
2026-08-20 Moved PCB project structure to a mainboard + sensorboard Began fleshing out a better board that uses a i2c bus extender to provide i2c over cat5 for longer distances for the sensor
    [HonkLock.kicad_pcb, HonkLock.kicad_sch, HonkLockSensorBoard.kicad_pcb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]
2026-09-01 Sensor board ready for mfg
    [HonkLockSensorBoard.kicad_pcb, HonkLockSensorBoard.kicad_sch, SOIC-8_L4.9-W3.9-H1.7-LS6.0-P1.27.step]
2026-09-01 Mainboard ready for mfg
    [HonkLock.kicad_pcb, HonkLock.kicad_sch, SOIC-8_L4.9-W3.9-H1.7-LS6.0-P1.27.step]
2026-09-01 Hit save before commit ya idjit
    [HonkLockSensorBoard.kicad_pcb]
2026-09-06 sent to mfg
    [CONN-TH_S3B-XH-A-LF-SN.step, HonkLock.kicad_pcb, HonkLock.kicad_sch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]
2026-09-27 added schematic PDFs, removed pointless project
2026-09-27 Updated readme, added sensorbox models
    [SensorBox.f3z, SensorBox.step]
2026-09-27 Fix schematic link case in README
    Corrected the case of the PCB directory in the schematic link.
2026-09-27 updated bom defaults
2026-09-30 Update Ethernet cable reference to cat5 cable
2026-10-01 production files
    [brainboard_bom.csv, brainboard_positions.csv, sensorboard_bom.csv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]
2026-10-07 fixed blastgate cad issues, added threaded-side for flexhose
    [BlastGate.f3z, BlastGate.step, BlastGateThreadedSide.f3z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]
2026-10-08 fix: BlastGate motor holes now actually appear at different sizes
    [BlastGate.f3z]
2026-10-09 feat: added "Honklock Gateway". Communicates with Arlec's RC210 remote powerpoint and/or ivac switch pro (contactor) to turn on the respective powerpoints. Honklock automations can trigger these to s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
2026-10-09 switched Gateway to ESP32-S3-Supermini like the rest of the honklock boards. The C3 was weird.
2026-10-10 fix: recreated the BlastGateThreadedSide so it actually scales correctly.
    [BlastGateThreadedSide.f3z, BlastGateThreadedSide.step]
